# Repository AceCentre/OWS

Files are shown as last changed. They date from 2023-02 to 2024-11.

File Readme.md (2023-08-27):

# Open Wireless Switch (OWS)

## What does this do?

You have a nrf52840 board that sends and a nrf52840 board that receives. We are demonstrating here how to do wireless switches with LOW POWER. nb. you can recieve kn software alone too. 

## Note: Docs and more info at https://docs.acecentre.org.uk/products/v/open-wireless-switch-ows/

## How?

Most wireless switches either use Radio (e.g. LoRa) or BLE HID to operate. The problem with BLE HID is that its power hungry and for switch users it cant really sleep. So this technique has a advertisement (advertisement) beacon which starts advertisement on a switch press. Full detail below.. 

On the advertisement (switch sending) board:
- When device sleeps and key button pressed first time, board wakes up. Once the LED lights the board is ready and you can start pairing or transmitting button data.
- When switch is pressed again board starts collecting button data into packages and advertise them.
- It then sends out packages. These data packages are changed every 100ms. Each package has recorded 10 buttons states with interval 10 ms(which in total 100ms).
- After some time of inactivity (5sec default) it will go back to sleep.

On the central (dongle) side:
- It scans BLE devices and for the MAC address device it receives package which has recorded button states over 100ms and then replays these states via USB keyboard (of course you could choose to do this as a joystick button or whatever. That I'm not too bothered about)

## Details

To try this out get two [nrf52840 feather express boards](https://www.adafruit.com/product/4062) from adafruit. Then load up the firmware for each board (its a arduino sketch - you want to first follow the guide [here](https://learn.adafruit.com/introducing-the-adafruit-nrf52840-feather/arduino-bsp-setup)). 

The firmware for the switch sending part is called *advertisement*. You need to add two switches -  one for the actual switch (use a switch jack) and a tactile swich for pairing. 

The firmware for the recievfing part is known as the *central* firmware. There should be defined a LED for indicating pairing. By default it's the red led of a nrf52840 Feather express.

When pairing button is pressed on the advertisement board it will send a specific pairing package and dongle receives this package and MAC address of the board it will listen for. The MAC is saved in flash memory and can be read later on start of dongle code.

Note - to save battery the advertisement board is set to sleep. Pressing the switch will wake it up - all in all this takes around 1 second. 

## Software only technique

So you can use a nrf52840 USB dongle to receive the switch press - or right now you could do it in software alone. See the python directory for this code. 

## Battery life estimates

When pressing key buttton and transmitting data, it consumes around 1000 uA.
In sleep mode it consumes 20 uA.
Good coin cell battery can have around 200 mAh.
So 200mAh/20uA = 10000 hrs in deep sleep mode.
10000hrs > 416 days > a bit more than a year.

But in general cheap batteries will have less capacity.

Consumption can also vary on different boads. My measurements were made with nrf52840 dongle.

## Hardware options

Pretty much any nrf52840 that you can load an arduino sketch onto. 
E.g. 

- [SEEED XIA0 nrf52840](https://shop.pimoroni.com/products/seeed-xiao-ble-nrf52840-supports-arduino-micropython-bluetooth5-0-with-onboard-antenna). Super small - will take a lipo if you solder onto the back batt pins
- [Adafruit nrf52840 express](https://shop.pimoroni.com/products/adafruit-feather-nrf52840-express). A great develeopment board. Has a spare button for you to use as either a pairing button or sending button. 
- [Adafruit itsybitsy nrf52840](https://shop.pimoroni.com/products/adafruit-itsybitsy-nrf52840-express-bluetooth-le). Same as the feather - but smaller and slight less flashy

And for the dongle
- This is nice as its all in one piece. [nrf52840 USB key](https://thepihut.com/products/nrf52840-usb-key-with-tinyuf2-bootloader-bluetooth-low-energy-mdbt50q-rx)

## Roadmap

- [x] Get basic code working
- [x] Add in pairing functionality
- [ ] Get video demo working
- [x] Add in low power features
- [ ] Adapt for x80 
- [x] Write demo code for PC (1/2 done. Can receive switches not send)
- [x] Create docs page on Ace site
- [x] Add ability to listen for more than one switch

## Licence

MIT

## Credits 

Will Wade, With a big nod to Prente Romiche/Saltillo and their aeroswitch. Note  - I have no idea if there's does exactly the same as this but a big clue was the fact they called it "Broadcast mode"

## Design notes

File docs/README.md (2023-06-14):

---
description: Introduction
---

# Open Wireless Switch (OWS)

{% hint style="danger" %}
This project is very much **experimental** and **work-in-progress**. We have not yet all the aims of the work and may never get there. We hope though that key learning may be useful for others developing wireless switches in the future - HID or BLE advertisement.&#x20;
{% endhint %}

### Background

There are a lot of various switches in existence. The typical connection for this has been a 3.5mm jack and socket. For a computer to understand this switch press, you require a box that turns this into something useful. This has typically been either a keypress, mouse press or a game controller button. \
\
Being tied to a lead can be a nuisance and risk for some people. We need a way of wireless switches existing. You can do this right now either using a form of Radio or Bluetooth - where several commercial switches and switch boxes exist and act as a Bluetooth Keyboard. But, this protocol can be both costly in respect of battery life and in overheads to support a Bluetooth keyboard.&#x20;

Some companies have developed lower power switches using Bluetooth, but this is proprietary, and the technique is not open to allow others to use.&#x20;

### Aim&#x20;

* Define an open protocol for wireless switches that allows anyone to develop a switch for any system - and equally; software developers support the OWS standard
* It should be as energy conservative as possible. People should expect a battery life of months and years - not hours and days.&#x20;
* It should work with no dongle on the receiving end. This is because many devices either have no port or it becomes difficult to access a port on a computer. But of course, having a dongle may be preferable and allow support to systems which can't/won't be supported
* It should have a way of working with physical devices too
* It should allow for 1+ multiple switches to use the same protocol
* It should have documented the response times&#x20;
* It should be open to scrutiny and improvements from anyone

### What does this do?

As of right now, we have working firmware for a Bluetooth chipset and software to receive the switches without the hardware. This is currently in python. We are open to discussion about the protocol and code.&#x20;

### What techniques have you considered?

Let's consider the different ways we can wirelessly create a switch (let us know if we have missed something!)

| Technique | Pros | Cons |
| --- | --- | --- |
| LoRa - Radio e.g 433 | Low low Low power | You would need a sender and receiving dongle. |
| IR | Low power | Unreliable, needs a dongle to receive and send |
| Chirp/Sound | Low power ? | Now hard to do this as Spotify bought chrip. Could design your own thing.. but environmental noise? Unreliable? Fiddly on designing receiving code |
| Bluetooth HID | Ubiquotous, Receiving easy | Power hungry. A lot of wasted bandwith |
| Bluetooth Beacon | Low Power, Recieving straightforward | Need a dongle on some devices where a background task can't run (e.g. iOS) |

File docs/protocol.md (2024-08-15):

# Protocol

{% hint style="info" %}
We are using a Nordic nrf52840 chipset for our work - but really any number of Bluetooth boards should support this technique as we are really just using the advertising feature of BLE.&#x20;
{% endhint %}

The Open Wireless Switch (OWS) system is designed to enable wireless communication between a switch (or button) and a central receiving device via Bluetooth Low Energy (BLE). This system is composed of two main components: the Advertisement (Switch Sending) board and the Central (Receiving) device. The switch board can enter pairing mode, send button press data, and enter sleep mode after a period of inactivity. The central device scans for BLE signals, pairs with the switch, and processes the button press data to simulate USB keyboard input or other actions.

#### Advertisement (Switch Sending) Board

The Advertisement board is responsible for sending BLE signals that represent button presses. It operates in two main modes: Pairing and Sending.

**1. Pairing Mode**

* **Activation**: Pairing mode is activated when the Pairing button on the Advertisement board is pressed.
* **Behavior**: When the device enters pairing mode, it wakes up from sleep and begins advertising a set of pairing packages. These packages contain specific data that allow the Central (Receiving) device to recognize and pair with the switch.
* **Purpose**: Pairing mode is essential for establishing a connection between the switch and the receiving device. It allows the receiving device to identify the switch's MAC address and prepare for subsequent data transmission.

**2. Sending Mode**

* **Switch Depress (Button Press)**:
  * When a button (or switch) on the Advertisement board is pressed, the board begins to collect button press data. This data is organized into packages.
  * Each data package represents the state of the button over a period of 100ms. Within this timeframe, the button state is sampled at 10ms intervals, resulting in 10 button states per package.
  * The data packages are advertised (broadcasted) via BLE at a rate of one package every 100ms.
* **Inactivity & Sleep Mode**:
  * After the button is released, if there is no further button activity for a specified period (default is 5 seconds), the Advertisement board will automatically enter sleep mode to conserve power.
  * In sleep mode, the device stops advertising and goes into a low-power state until it is reawakened by either another button press or the Pairing button.

#### Central (Receiving) Device

The Central device is responsible for scanning for BLE signals from the Advertisement board, pairing with it, and processing the received button press data.

**1. Pairing Mode**

* **Scanning**:
  * The Central device continuously scans for BLE devices in the vicinity. When it detects the pairing packages from the Advertisement board, it reads the MAC address and pairs with the device.
  * Pairing allows the Central device to recognize the specific switch and prepare to receive button press data.

**2. Button Press Data Handling**

* **Receiving Data Packages**:
  * After pairing, the Central device begins to receive the advertised data packages from the Advertisement board whenever the button is pressed.
  * Each package contains the button states recorded over 100ms. These packages are transmitted and received in real-time.
* **Processing and Replay**:
  * Upon receiving a data package, the Central device processes the button states contained within it.
  * The Central device can then replay these button states via USB as if they were keyboard inputs. This allows the button press on the switch to be translated into a corresponding action on the Central device, such as pressing a specific key on a keyboard.
  * The system is flexible, allowing the received data to be interpreted in different ways (e.g., as joystick input or other control mechanisms).

#### Detailed Specifications

**1. Manufacturer ID**

* **Purpose**: The Manufacturer ID is a unique identifier used in BLE advertising packets to distinguish the specific manufacturer or type of device. In the OWS system, this ID is used to identify the Advertisement board during the pairing process and when sending button press data.
* **Value**: The Manufacturer ID used in the OWS system is `0xFFFF`.
* **Usage**:
  * This ID is embedded in the BLE advertising packets sent by the Advertisement board.
  * The Central (Receiving) device listens for advertising packets with this specific Manufacturer ID to identify and pair with the switch.
  * The Manufacturer ID is included in every data package, allowing the Central device to verify the source of the received data.

**2. Button Pair Packages**

* **Purpose**: The button pair packages are special BLE advertising packets sent when the Advertisement board enters pairing mode. These packages contain a predefined data structure that allows the Central device to recognize the board and establish a connection.
* **Package Structure**:
  *   The button pair package is a fixed-size byte array with the following structure:

      ```csharp
      csharpCopy code[0xFF, 0xFF, 0x9C, 0x7C, 0x00, 0x00, 0x00, 0x00, 0x00, 0x00, 0x00, 0x00, 0x00, 0x00, 0x00, 0x00, 0x00, 0x00, 0x00, 0x00]
      ```
  * **Fields**:
    * **Bytes 0-1**: Manufacturer ID (`0xFFFF`).
    * **Bytes 2-3**: Pairing Identifier (`0x9C7C`).
    * **Bytes 4-19**: Reserved for additional data or padding (all `0x00` in this case).
* **Functionality**:
  * When the Pairing button on the Advertisement board is pressed, the board begins broadcasting these pairing packages.
  * The Central device scans for these packages and, upon detecting the correct Manufacturer ID and Pairing Identifier, will pair with the switch.

**3. Button Press Data Packages**

* **Purpose**: The button press data packages are BLE advertising packets sent by the Advertisement board when a button is pressed. These packages contain recorded button states over a short period (100ms) and are used by the Central device to emulate input actions.
* **Package Structure**:
  *   Each button press data package contains the following fields:

      ```java
      javaCopy code[Manufacturer ID (2 bytes), Package Index (1 byte), Button Data (4x4 bytes)]
      ```
  * **Fields**:
    * **Manufacturer ID (Bytes 0-1)**: `0xFFFF`.
    * **Package Index (Byte 2)**: A byte that increments with each new package, allowing the Central device to track the sequence of packages.
    * **Button Data (Bytes 3-18)**: A 4x4 matrix where each row represents a different button, and each column represents a 10ms interval within the 100ms timeframe. Each entry in this matrix is a 4-bit value (0 or 1), indicating whether the button was pressed (`1`) or not (`0`) at that specific time interval.
* **Data Layout Example**:
  *   For a setup with 4 buttons, a data package might look like this:

      ```csharp
      [0xFF, 0xFF, 0x01, 0x0A, 0x05, 0x03, 0x0F, 0x07, 0x00, 0x00, 0x00, 0x00, 0x00, 0x00, 0x00, 0x00, 0x00, 0x00]
      ```

      * **Manufacturer ID**: `0xFFFF` (Bytes 0-1)
      * **Package Index**: `0x01` (Byte 2)
      * **Button Data**:
        * Button 1 states over 100ms: `0x0A` (Byte 3)
        * Button 2 states over 100ms: `0x05` (Byte 4)
        * Button 3 states over 100ms: `0x03` (Byte 5)
        * Button 4 states over 100ms: `0x0F` (Byte 6)
        * Remaining bytes are padded with `0x00` for alignment.
* **Button States Interpretation**:
  *   Each button state byte can be interpreted as a sequence of bits representing the state of the button at each 10ms interval within the 100ms timeframe. For example, the byte `0x0A` (Button 1) could represent the following binary sequence:

      ```
      00001010
      ```

      * This indicates that the button was pressed during the 4th and 2nd 10ms intervals and released during the others.

**4. Buttons Configuration**

* **Number of Buttons**: The system supports up to 4 buttons by default, but this can be extended if needed by adjusting the data package format.
* **Button Identifiers**:
  * Buttons are identified numerically (Button 1, Button 2, etc.).
  * Each button’s state is recorded separately in the data package, allowing the Central device to determine which button was pressed and when.

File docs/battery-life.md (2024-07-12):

# Battery life

When transmitting data, an nrf52840 dongle consumes around 1000 uA (1mA)\
In sleep mode, it consumes 20 uA. \
A Good coin cell battery can have around 200 mAh. \
\
So sleep battery life. 200mAh/20uA = 10000 hrs in deep sleep mode. 10000hrs > 416 days > a bit more than a year.

In transmitting:\
\- Single press activates advertising, and if there is no next activity for half a second then advertising turns off. \
\- So we have a consumption of 1mA during half second for a single press. So about Coin cell has 200 mAh -> 200 \* 3600 mAsec or **7200 single presses.**&#x20;

How long will then a average coin cell battery last in sleep mode only?

* 500 mAh / 0.02 mA = 25,000 hours ≈ 1,042 days or about 2.85 years How long will the battery last in active mode only?
* 500 mAh / 1 mA = 500 hours ≈ 20.83 days”

But in general, cheap batteries will have less capacity.

**If we have a 1000 mAh battery/ 0.02 mA = 50,000 hours ≈ 2,083 days or about 5.7 years sleep mode. Active mode only: 1000 mAh / 1 mA = 1000 hours ≈ 41.67 days**

**In our real world tests this stands up.**\
**We had our code running actively (a switch press per second) We calculated**\
\
**3392945** switch presses\
in a total of **809hours** approx 33 days. It was still going and we decided to read its battery voltage where we read 3.7. It starts at 4.2.

### How does this compare with HID?

2532 uA (2.532 milliamperes) constant draw is seen on an HID connection with an nrf52840. So it consumes more than 2.5x more power.&#x20;

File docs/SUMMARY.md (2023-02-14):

# Table of contents

* [Open Wireless Switch (OWS)](README.md)
* [Protocol](protocol.md)
* [How to get started](how-to-get-started.md)
* [Battery life](battery-life.md)
* [Supported Hardware](supported-hardware.md)
* [Roadmap](roadmap.md)
* [Credits](credits.md)
* [Contributing](contributing.md)

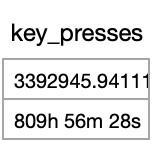
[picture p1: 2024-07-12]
docs/.gitbook/assets/image.png

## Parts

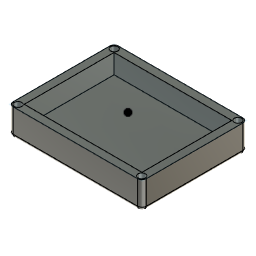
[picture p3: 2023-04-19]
cad-files/parts/_part_1.8a450ea1-394b-4fa4-8eaf-b81ad2c45062.png

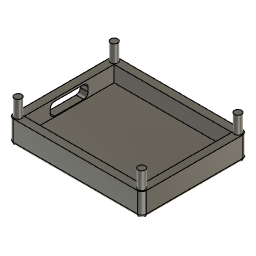
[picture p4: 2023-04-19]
cad-files/parts/_part 2.292399b7-fae1-4982-abd4-8dabb6284c28.png

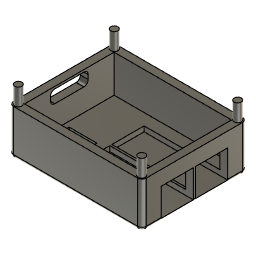
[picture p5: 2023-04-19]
cad-files/parts/_part 2.2604b093-3b9d-40d1-b236-c376f4c4fee4.png

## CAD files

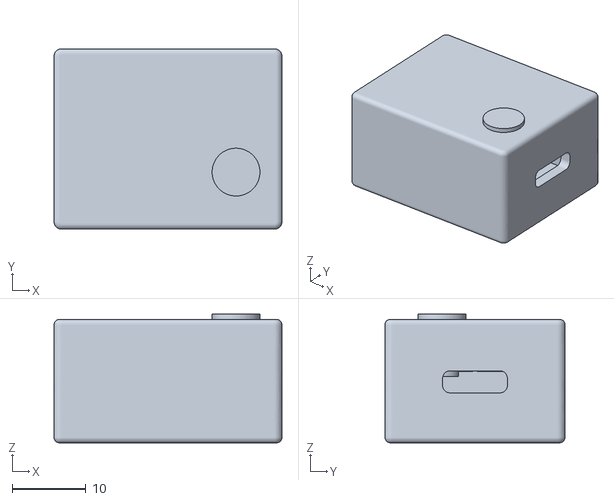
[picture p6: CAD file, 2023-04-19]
cad-files/STL/Assembly_final v6.stl
31.0 x 24.5 x 17.5

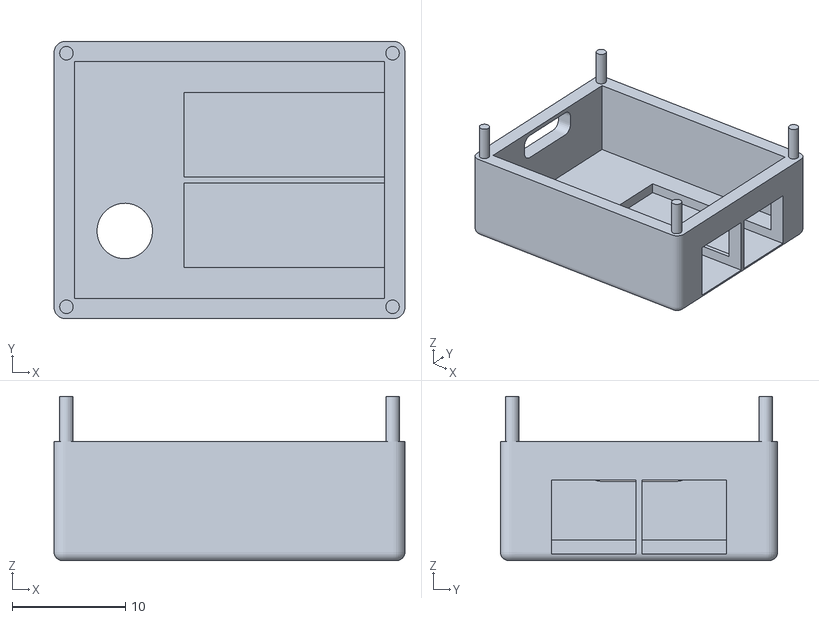
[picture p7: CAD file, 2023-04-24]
cad-files/STL/Uper part.stl
31.0 x 24.5 x 14.5

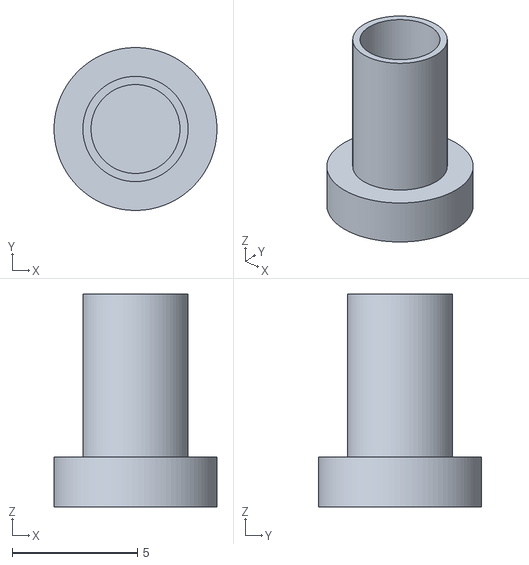
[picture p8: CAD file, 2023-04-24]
cad-files/STL/button v2.stl
6.50 x 6.50 x 8.50

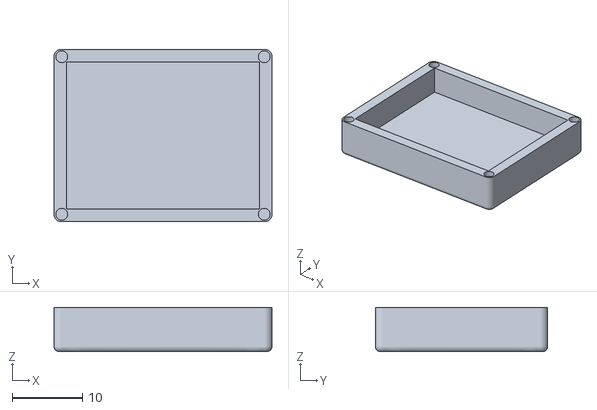
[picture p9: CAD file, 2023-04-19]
cad-files/STL/lower part.stl
31.0 x 24.5 x 6.30

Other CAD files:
cad-files/parts/_Assembly_final.8fc7a0d0-9807-4fcd-912e-7f79d4c8e8f5.f3d
cad-files/parts/_assembly.eede8621-9753-4f55-8028-582a984d6d41.f3d
cad-files/parts/_part 2.2604b093-3b9d-40d1-b236-c376f4c4fee4.f3d
cad-files/parts/_part 2.292399b7-fae1-4982-abd4-8dabb6284c28.f3d
cad-files/parts/_part 2.99b838c8-83c5-4aec-84e9-91cd62201415.f3d
cad-files/parts/_part 2.af4cea7a-fd4b-4f0e-be85-1c45aad45d52.f3d
cad-files/parts/_part 2.f3cbd399-88e2-494d-b35e-1f1d8a7854d6.f3d
cad-files/parts/_part 2.f688ebcb-d17f-404a-8e90-d002cc2e3537.f3d
cad-files/parts/_part_1.318b750a-d903-4d5c-bca3-ea630c4a2858.f3d
cad-files/parts/_part_1.8a450ea1-394b-4fa4-8eaf-b81ad2c45062.f3d

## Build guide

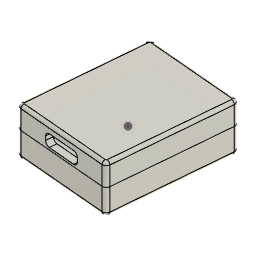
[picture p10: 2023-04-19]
cad-files/parts/_assembly.eede8621-9753-4f55-8028-582a984d6d41.png

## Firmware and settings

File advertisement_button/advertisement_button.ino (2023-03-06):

#include <bluefruit.h>

//#define DEBUG                          // disables deep sleep and enables waiting for serial port

#define LED LED_BLUE                    // status led
#define PAIR_BUTTON A0                 // pairing button pin

uint8_t n_buttons = 4;                 // number of buttons to init and advertise
uint8_t button_pins[] = {A1,A2,A3,A4}; // buttons pins
bool pressed_button = 0;               // flag to check if there buttons pressed

uint32_t inactivity_timeout = 500;     // stop advertising buttons data after this timeout
uint32_t sleep_timeout = 5000;         // go to sleep mode after this timeout 
uint32_t pairing_timeout = 500;        // stop advertising pairing pakcage after this timeout     

// transmit power in dBm
// Supported values: -40dBm, -20dBm, -16dBm, -12dBm, -8dBm, -4dBm, 0dBm, +2dBm, +3dBm, +4dBm, +5dBm, +6dBm, +7dBm and +8dBm 
int8_t tx_power = 4;
 
uint32_t last_action = 0;

uint16_t button_packs[] = {0,0,0,0};
uint8_t package_size = 8;
uint8_t package_i = 0;
uint8_t sample_n = 0;
uint16_t set_bit;

uint8_t button_states[] = {0,0,0,0};
uint8_t button_states_prev[] = {0,0,0,0};

uint8_t pair_button_state = 0;
uint8_t pair_button_state_prev = 0;

uint32_t read_interval = 30;

uint8_t pair_package[] = {0xFF,0xFF,0x9C,0x7C,0,0,0,0,0,0,0,0,0,0,0,0,0,0,0,0};

struct adv_package
{
  uint16_t manufacturer_id;
  uint8_t  package_index;
  uint8_t button_packs[4][4];
} buttons_data = {
  .manufacturer_id = 0xFFFF,
};

bool pairing = false;
bool sampling = false;

void update_advertisement_data() {  
  buttons_data.package_index = package_i;

  for(uint8_t i = 0; i < n_buttons; i++) {
    for(uint8_t j=3;j>0;j--) {
      buttons_data.button_packs[j][i] = buttons_data.button_packs[j-1][i];
    }
    buttons_data.button_packs[0][i] = button_packs[i];
  }
  
  Bluefruit.Advertising.clearData();    
  Bluefruit.Advertising.addManufacturerData(&buttons_data, sizeof(buttons_data));
}

void set_pair_data() {
  Bluefruit.Advertising.clearData();    
  Bluefruit.Advertising.addManufacturerData(pair_package, sizeof(pair_package));
}

void setup_advertisment(void)
{   
  // Advertising packet
  update_advertisement_data();
  //Bluefruit.Advertising.addFlags(BLE_GAP_ADV_FLAGS_LE_ONLY_GENERAL_DISC_MODE);
  Bluefruit.Advertising.setType(BLE_GAP_ADV_TYPE_NONCONNECTABLE_SCANNABLE_UNDIRECTED);

  Bluefruit.Advertising.restartOnDisconnect(true);
  Bluefruit.Advertising.setInterval(32, 32);    // in units of 0.625 ms
  Bluefruit.Advertising.setFastTimeout(30);      // number of seconds in fast mode
  //Bluefruit.Advertising.start(ADV_TIMEOUT);      // Stop advertising entirely after ADV_TIMEOUT seconds 
}

void enter_deepsleep() {
  digitalWrite(LED, LOW);                     
  pinMode(button_pins[0],  INPUT_PULLUP_SENSE);
  sd_power_system_off();
}

void setup() 
{
  set_bit = 1 << package_size;
  
  // configure buttons as input with a pullup (pin is active low)
  for(uint8_t i = 0; i < n_buttons; i++) {    
    pinMode(button_pins[i], INPUT_PULLUP);
  }
  
  pinMode(PAIR_BUTTON, INPUT_PULLUP);
  
  Serial.begin(115200);
  #ifdef DEBUG                      
    while ( !Serial ) delay(10);   // for nrf52840 with native usb
  #endif

  Bluefruit.begin();
  Bluefruit.setTxPower(4);
  
  // Set up advertisement
  setup_advertisment();

  /*
  ble_gap_addr_t button_address = Bluefruit.getAddr();
  Serial.print("Button MAC address: ");
  Serial.printf("%X");
  for(int i=1;i<6;i++) {
    Serial.printf(":%X", button_address.addr[i]);    
  }
  Serial.println();
  */
  
  Serial.printf("Board is set up after: %ums\n", (millis()-last_action));
  pinMode(LED, OUTPUT);
  digitalWrite(LED, HIGH);
  last_action = millis();
}

void loop() {
  // reading buttons states
  pressed_button = false;
  for(uint8_t i = 0; i < n_buttons;i++) {
    button_states[i] = !digitalRead(button_pins[i]);
    if(button_states[i] != button_states_prev[i]) {
      sampling = true;
      pairing = false;

      last_action = millis();
    }
    if(button_states[i] == 1){
      pressed_button = true;
    }
    button_states_prev[i] = button_states[i];
  }

  // reading pairing button state
  pair_button_state = ! digitalRead(PAIR_BUTTON);
  if(pair_button_state == 1 && pair_button_state_prev == 0) {    
    set_pair_data();
    
    if(!Bluefruit.Advertising.isRunning()) {
      Bluefruit.Advertising.start();
      Serial.println("Starting pairing advertisement");
    }

    pairing = true;        
    sampling = false;

    last_action = millis();
  }
  pair_button_state_prev = pair_button_state;

  
  if(sampling) {
    if((millis() - last_action) > inactivity_timeout && pressed_button == false && Bluefruit.Advertising.isRunning()) {
      Bluefruit.Advertising.stop();
      Serial.println("Stopping button advertisement");
      Serial.println("clearing advertising data");
      for(uint8_t i = 0; i < n_buttons; i++) {
        for(uint8_t j=0;j<4;j++) {
          //Serial.printf("%u:%u ", i,j);
          buttons_data.button_packs[i][j] = 0;
        }
        //Serial.println();
      }
      //Serial.println();
      
      sampling = false;
            
    } else {
      if(sample_n < package_size) {
        if(sample_n == 0){
          //Serial.printf("Gathering new package\n");
        }

        for(uint8_t i = 0; i < n_buttons; i++) {
          //Serial.printf("Button #%u state: %u\n", (i+1), button_state);
          if(button_states[i]) {
            button_packs[i] = button_packs[i] | set_bit;
          }
          button_packs[i] = button_packs[i] >> 1;
        }
        sample_n++;  
      } else {
        //Serial.printf("Package gathered; id: %X; sample: %X\n", package_i, button_packs[0]);
        update_advertisement_data();
        
        // start button avertising after package was gathered 
        if(!Bluefruit.Advertising.isRunning()) {
          Bluefruit.Advertising.start();
          Serial.println("Starting button advertisement");
        }
        
        for(uint8_t i = 0; i < n_buttons; i++) {
          button_packs[0] = 0;
        }
        
        sample_n = 0;
        package_i++;        
      }
    }
  }

  if(pairing) {
    if((millis() - last_action) > pairing_timeout && Bluefruit.Advertising.isRunning()) {
      Bluefruit.Advertising.stop();
      pairing = false;
      Serial.println("Stopping pairing advertisement");      
    }    
  }

  #ifndef DEBUG
  if((millis() - last_action) > sleep_timeout && pressed_button == false) {
    enter_deepsleep();
  }
  #endif
  
  delay(read_interval);
}

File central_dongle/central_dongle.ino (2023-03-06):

#include <bluefruit.h>
#include "Adafruit_TinyUSB.h"
    
#include <InternalFileSystem.h>
using namespace Adafruit_LittleFS_Namespace;
File file(InternalFS);
#define MAC_FILENAME    "/button_mac.txt"

#define PAIR_LED LED_BLUE                // led for indicating pairing
uint8_t n_pair_blinks = 3;        // number of blinks during pairing  
uint32_t blink_interval = 500;    // interval of blinks during pairing 

uint8_t n_buttons = 4;  // number of buttons to receive
uint8_t buttons_hid_actions[] = {HID_KEY_1, HID_KEY_2, HID_KEY_3, HID_KEY_4}; // hid action for each button that will be sent via USB

uint8_t const desc_hid_report[] =
{
  TUD_HID_REPORT_DESC_KEYBOARD()
};

Adafruit_USBD_HID usb_hid(desc_hid_report, sizeof(desc_hid_report), HID_ITF_PROTOCOL_KEYBOARD, 2, false);

uint8_t keycode[6] = { 0 };

bool keyboard_state = false;

uint8_t pair_package[] = {0x15, 0xFF, 0xFF, 0xFF, 0x9C, 0x7C, 0, 0, 0};

bool indicate_pair = false;

uint8_t button_mac_arr[6] = { 0 };

uint32_t last_update = 0;
uint32_t last_update_diff = 0;

uint8_t received_package[4];
uint8_t package_i = 255;
uint8_t package_size = 8;

uint8_t replay_package[4];
uint8_t  replay_i = 255;
uint32_t replay_interval = 30;

void get_mac_from_file() {
  Serial.println("Reading saved mac");

  file.open(MAC_FILENAME, FILE_O_READ);
  if(file) {
    Serial.println("File present");
    uint32_t readlen;
    readlen = file.read(button_mac_arr, 6);
    
    if(readlen == 6){
      Serial.print("Saved mac of button: ");
      Serial.printBuffer(button_mac_arr, 6, ':');
      Serial.println();
    } else {
      Serial.println("Unsuccessful reading of mac");
      memset(button_mac_arr, 0, 6);      
    }

    file.close();    
  } else {
    Serial.println("File doesn't exist");
  }
}

void save_mac_to_file() {
  Serial.println("Saving mac into file");
  
  file.open(MAC_FILENAME, FILE_O_WRITE);
  if(file) {
    file.write(button_mac_arr, 6);
    file.close();

    Serial.println("Mac saved");
  } else {
    Serial.println("Failed to open file");
  }
}

void print_full_advertisement(ble_gap_evt_adv_report_t* report) {
    Serial.println();
    Serial.println("Advertisement package: ");
    Serial.println("Timestamp Addr              Rssi Data");
    Serial.printf("%09d ", millis());    
    // MAC is in little endian 
    Serial.printBuffer(report->peer_addr.addr, 6, ':');
    Serial.print(" ");
    Serial.print(report->rssi);
    Serial.print("  ");
    Serial.printBuffer(report->data.p_data, report->data.len, '-');
    Serial.println();  
}

bool target_device(uint8_t* received_mac) {
  for(int i = 0; i<6; i++) {
    if(received_mac[i] != button_mac_arr[i]) {
      return false;
    }
  }

  return true;
}

bool repairing_package(uint8_t* received_package) {
  for(int i = 0; i<9; i++) {
    if(received_package[i] != pair_package[i]) {
      return false;
    }
  }

  return true;
}

void unpack_package(uint8_t* received_package) {
  //Serial.printf("Unpacking package: %X\n", received_package);
  for(uint8_t i=0; i<package_size; i++) {
    //Serial.printf("%u; button: ", i);
    for(uint8_t j = 0; j < n_buttons; j++) {
    if(received_package[j] & 1) {
      keycode[j] = buttons_hid_actions[j];            
      //Serial.printf("pressed\n");
    } else {
      keycode[j] = 0;      
      //Serial.printf("released\n");      
    }

    received_package[j] = received_package[j] >> 1;
    }
    
    while (!usb_hid.ready()) {}
    usb_hid.keyboardReport(0, 0, keycode);

    delay(replay_interval);        
  }
}

void scan_callback(ble_gap_evt_adv_report_t* report)
{
  //print_full_advertisement(report);

  if(repairing_package(report->data.p_data)) {
    Serial.println("Got pairing package");
    
    if(!target_device(report->peer_addr.addr)) {
      Serial.print("Old device: ");
      Serial.printBuffer(button_mac_arr, 6, ':');
      Serial.println();
      for(int i=0; i<6; i++){
        button_mac_arr[i] = report->peer_addr.addr[i];
      }
      Serial.print("New device paired: ");
      Serial.printBuffer(button_mac_arr, 6, ':');
      Serial.println();
      
      save_mac_to_file();

      indicate_pair = true;      
    }else {
      Serial.println("Device already paired");
    }
  } else if(target_device(report->peer_addr.addr)) {    
    if(package_i != report->data.p_data[4]) {
      last_update_diff = millis() - last_update;
      last_update = millis();
      Serial.printf("Since last update: %u; Received package: %X-%X-%X-%X-%X\n", last_update_diff, report->data.p_data[4], report->data.p_data[5], report->data.p_data[6], report->data.p_data[7], report->data.p_data[8], report->data.p_data[9]);
      
      package_i = report->data.p_data[4];
      for(uint8_t i = 0; i < n_buttons; i++) {
        received_package[i] = report->data.p_data[i+5];
      }

    }
  }

  // For Softdevice v6: after received a report, scanner will be paused
  // We need to call Scanner resume() to continue scanning
  Bluefruit.Scanner.resume();
}

void setup() 
{
  pinMode(PAIR_LED, OUTPUT);

  Serial.begin(115200);  
  usb_hid.begin();
  InternalFS.begin();
    
  while( !TinyUSBDevice.mounted() ) delay(1);
  
  //while ( !Serial ) delay(10);   // for nrf52840 with native usb
  Serial.println("USB mounted");

  get_mac_from_file();

  Bluefruit.begin(0, 1);
  Bluefruit.setTxPower(4);    // Check bluefruit.h for supported values
  Bluefruit.setName("Bluefruit52");

  // Start Central Scan
  Bluefruit.setConnLedInterval(100);
  Bluefruit.Scanner.setRxCallback(scan_callback);
  Bluefruit.Scanner.start(0);
  
  delay(500);
  last_update = millis();
  
  Serial.println("Scanning for button");
    
}

void loop() 
{
  if(indicate_pair) {
    for(int i=0; i<n_pair_blinks; i++){
      digitalWrite(PAIR_LED, HIGH);
      delay(blink_interval);
      digitalWrite(PAIR_LED, LOW);
      delay(blink_interval);
    }

    indicate_pair = false;
  }
  if(replay_i != package_i) {    
    replay_i = package_i;
    
    Serial.printf("replaying package %u: ", replay_i);
    for(uint8_t i=0;i<n_buttons;i++){
      replay_package[i] = received_package[i];
      Serial.printf("%X ", replay_package[i]);
    }
    Serial.println();

    unpack_package(replay_package);    
  }
}

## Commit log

2023-02-17 multiple swiches
    Button:
    - Number of buttons that will be sampled and advertised can be configured at line
    - Buttons pins can be set at line 9.
    - Transmission power can be changed at line 18.
    Dongle code:
    - Number of buttons to receive and replay can be set at line 13
    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
2023-03-06 fixing to work with the raytac dongle and feather express
    [advertisement_button.ino, central_dongle.ino]
2023-04-19 uploading casing
    [Assembly_final v6.stl, Uper part.stl, _Assembly_final.8fc7a0d0-9807-4fcd-912e-7f79d4c8e8f5.f3d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]
2023-04-24 altered STL for sizing
    [Uper part.stl, button v2.stl]
2024-06-26 GITBOOK-12: updates with battery life
2024-07-12 GITBOOK-13: real world battery test
2024-11-27 adding in target uuid filtering
